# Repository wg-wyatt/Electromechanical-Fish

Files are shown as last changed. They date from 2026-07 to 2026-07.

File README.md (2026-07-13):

# Bio-Inspired Robotic Fish

## Overview

<p align="center">
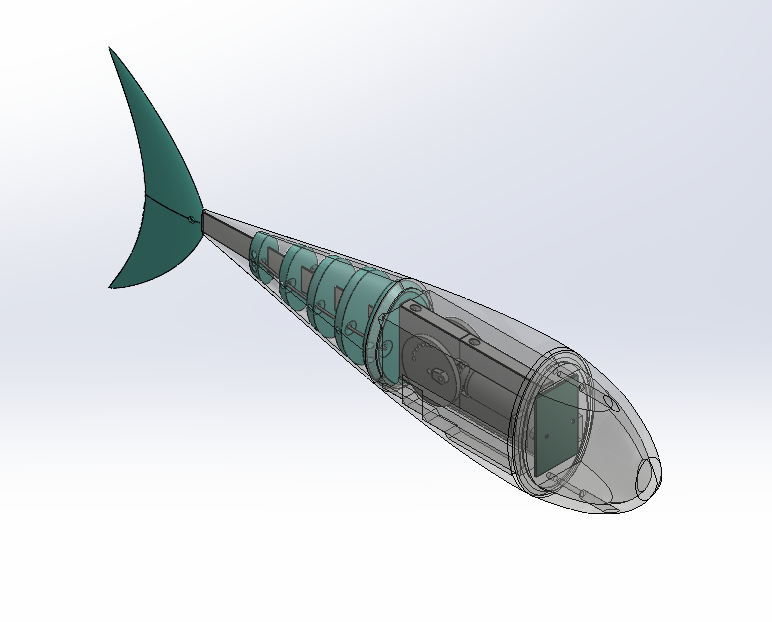
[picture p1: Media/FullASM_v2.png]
Bio-Inspired Robotic Fish Overview
  
</p>

<p align="center">
  <details>
    <summary>🔍 <b>Click to expand CAD Section & Internal Architecture View</b></summary>
    <br>
    <p align="center">
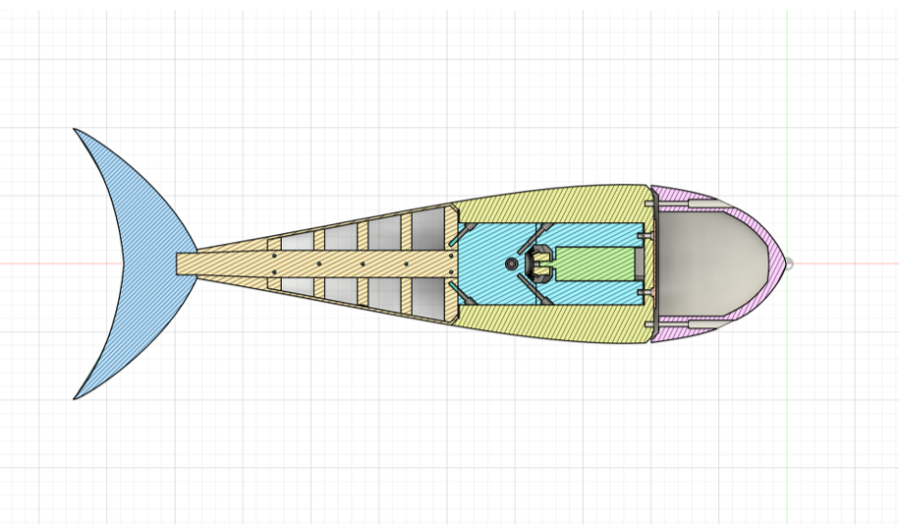
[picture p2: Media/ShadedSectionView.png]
Internal Architecture Blueprint
      
    </p>
  </details>
</p>

---

The Bio-Inspired Robotic Fish is an engineering project that uses undulatory propulsion (fish-like swimming) as an alternative to conventional propellers. The objective is to develop a modular robotic platform that mimics the biomechanics of carangiform swimmers using a mechanically actuated flexible body.

The project combines mechanism design, computational fluid dynamics (CFD), and rapid prototyping to integrate a rotary system that converts torque to smooth, oscillatory motion within a biomimetic frame. The project was developed as part of a physical prototyping class in which students designed and manufactured physical models for a speed competition.

---

## Project Objectives

The primary objectives of the project are to:

- Develop a mechanical system capable of converting a single rotary input into a traveling wave along a flexible body.
- Design a hydrodynamically efficient external body inspired by biological swimmers.
- Create a modular internal architecture that supports rapid iteration of actuators and transmission mechanisms.
- Evaluate propulsion concepts through physical prototyping.

---

## Problem Description

Conventional underwater vehicles primarily rely on propellers for propulsion. While effective, propellers generate noise, expose moving components, and are not optimized for maneuverability in confined or sensitive environments.

Many aquatic organisms instead produce propulsion by generating traveling waves along their bodies and fins. This method provides efficient thrust generation while enabling precise maneuvering and reduced acoustic signature.

This project explores the engineering challenges associated with reproducing this biological locomotion using practical mechanical systems and accessible manufacturing techniques. 

---

## Exterior Design

The external body is designed to balance hydrodynamic performance, manufacturability, and accessibility to internal components. Multiple design iterations are evaluated using CAD modeling and Computational Fluid Dynamics (CFD) to investigate body shape, drag characteristics, and flow behavior before fabrication.

Design considerations include:

- Streamlined body geometry
- Hydrodynamic efficiency
- Internal packaging volume
- Modular outer shell construction
- Ease of assembly and maintenance

CFD analysis was used during the design process to compare body geometries. Specific attention was given to drag coefficients when examining mechanisms to improve swimming velocity. Detailed CFD setup, mesh generation, and results are available in the analysis report:

[CFD Analysis Report](Analysis/CFD_report.pdf)

Shown in **Figure 1** is the final external design, which was modified from the surface model with the lowest drag coefficient and modularized into three compartments. Each compartment houses the electronics, the rotary actuator, and the spine used to generate the oscillation, respectively. 

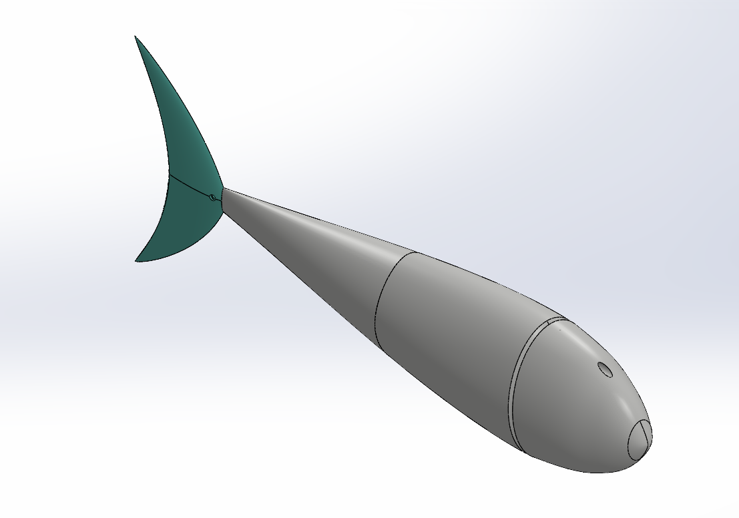
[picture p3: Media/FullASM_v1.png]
Robotic Fish Final Design


---

## Interior Design

The internal mechanical architecture focuses on generating undulatory motion using a compact rotary actuator and transmission mechanism. This design uses continuous rotary motion to produce a controlled traveling wave capable of propagating through a compliant tail section.

Current design investigations include:

- Motion transmission mechanisms
- Linkage geometry optimization
- Flexible body integration
- Waterproof packaging strategy

**Figure 2** displays the complete internal architecture, which is divided into three functional modules:

- *Module 1 (Front):* Houses the main electronics and battery payload. A secure gasket seals the interface between the first and second modules.

- *Module 2 (Central):* Encloses the motor gearbox and features integrated negative space for custom buoyancy weighting.

- *Module 3 (Rear):* Consists of the main undulating spine enclosed in a compliant silicone sleeve.

The gearbox mounts directly to the largest node of the spine, allowing the entire drive sub-assembly to slide seamlessly into the central chassis. Fastening the gearbox to the forward wall of Module 2 compresses the silicone sleeve, establishing a robust, watertight seal between the drive and tail sections.

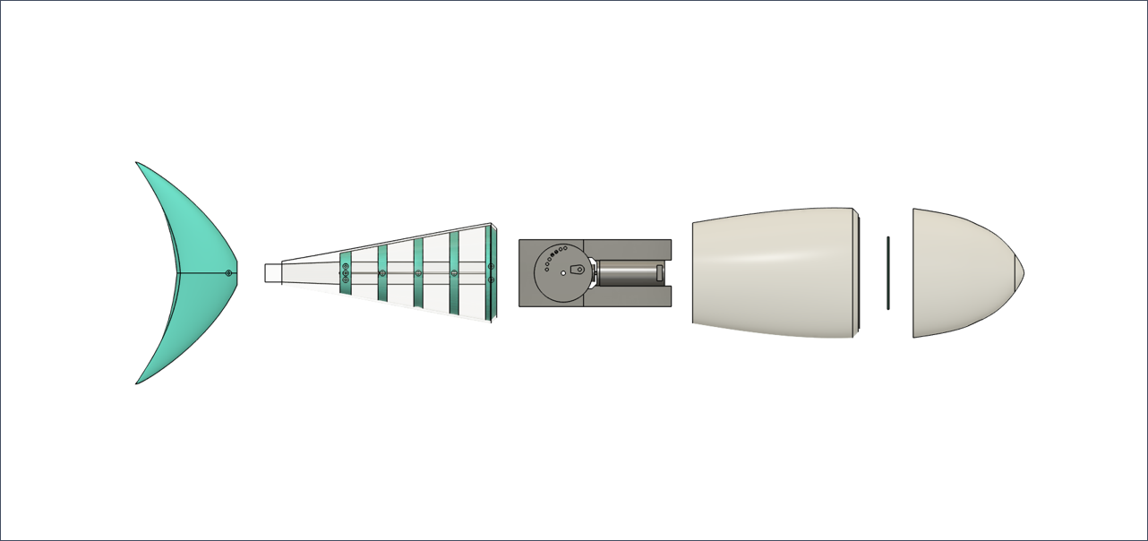
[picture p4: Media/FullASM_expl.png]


**Figure 3** illustrates the internal drive system, which is engineered to generate reciprocating motion that mimics the tandem contraction and expansion of biological fish musculature.

- *Torque Transmission:* A central drive gear translates power to two counter-rotating flywheels to balance inertial forces.

- *Adjustable Amplitude:* Multiple pinholes are integrated into the flywheels to allow for rapid physical experimentation with different oscillatory wave heights.

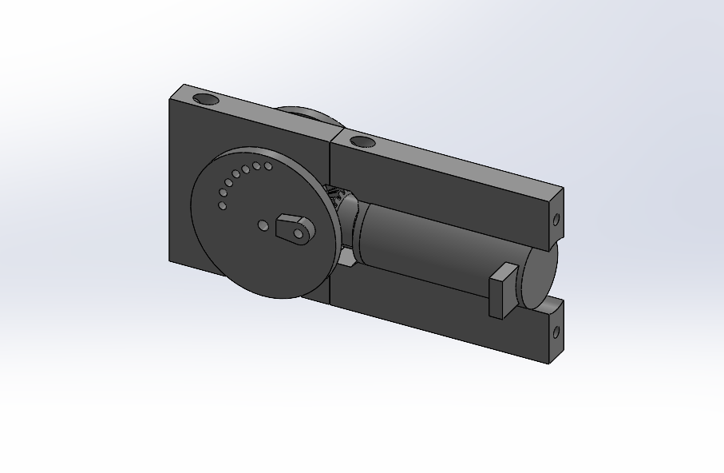
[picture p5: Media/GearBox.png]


<details>
  <summary>🔍 <b>Exploded View</b></summary>
  <p>
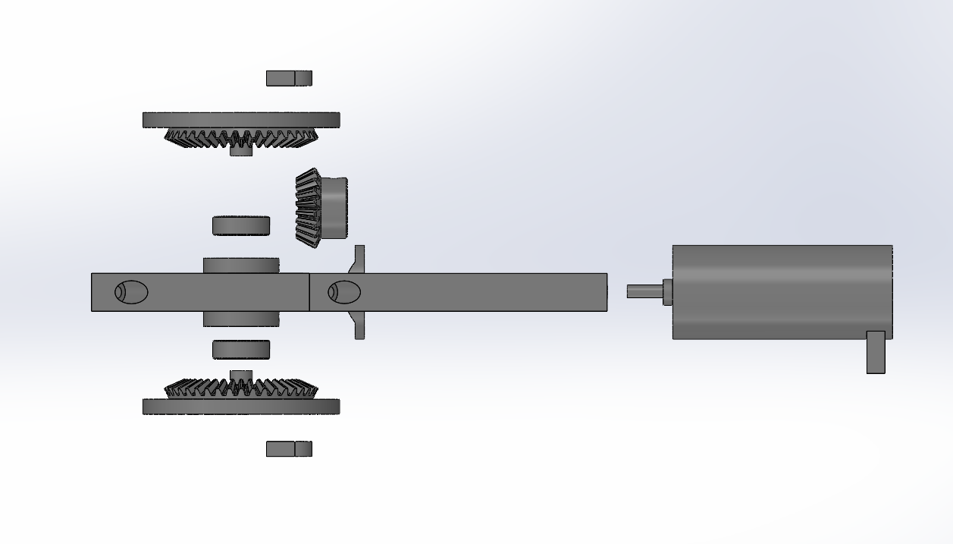
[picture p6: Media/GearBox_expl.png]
Exploded View
    
  </p>
</details>

**Figure 4** illustrates the spine system, which translates the rotational crank motion of the flywheels into the undulating wave profile that drives the tail fin. A flexible spine runs through five distinct nodes, which are linked to the flywheels via rigid PLA shafts. These push-pull linkages offer significantly higher structural rigidity and more precise force transmission than traditional steel cables or high-tensile ropes.

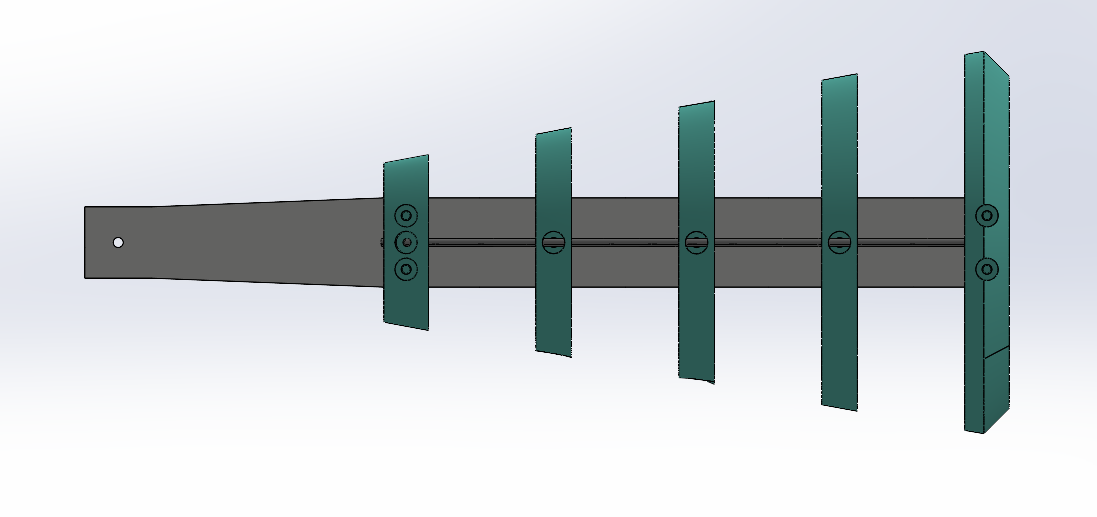
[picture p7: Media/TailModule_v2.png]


---

## Manufacturing

The robotic fish is designed around rapid prototyping techniques that enable fast design iteration while minimizing manufacturing cost and complexity.

### Pirmary Fabrication

**3D Printing:** 
- The main chassis modules
- The gear housings and components
-  Modular spine nodes
Components are designed with targeted orientation optimization to maximize layer adhesion against cyclic shear stresses generated during undulatory swimming.

**Laser Cutting:**
The central structural spine is precision laser-cut from acrylic sheets. This provides the bending stiffness required to guide the wave profile while maintaining structural rigidity.

**Silicone Molding:**
**Figure 5** illustrates the multi-part mold designed in SOLIDWORKS and 3D-printed to form the soft robotic component. A silicon epoxy is cast within the mold to produce the compliant outer casing required to seal the spine.

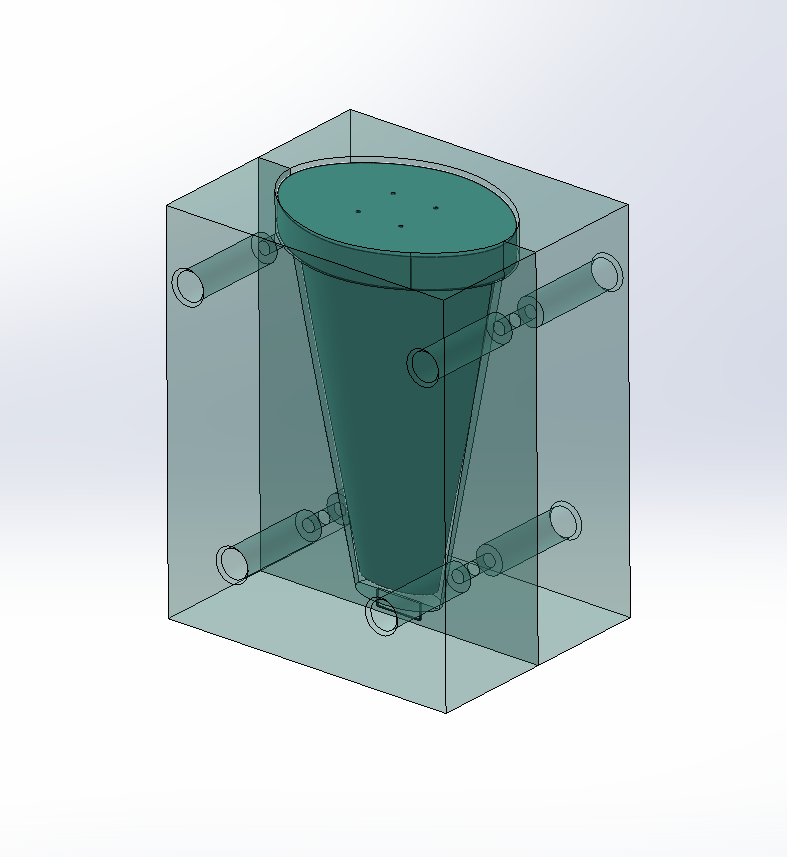
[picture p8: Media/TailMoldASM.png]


---

## Prototype Demonstration

The prototype was evaluated multiple times to optimize buoyancy and wave amplitude. **Figure 6** is a video log of a velocity test.

[<!-- Insert demonstration video here -->
<video src="Media/Prototype_Demo.mp4" width="100%" controls></video>](https://github.com/user-attachments/assets/9273b07a-2a17-41cb-9441-51ac28899b79)

---

## Skills Demonstrated

### Mechanical Design

- CAD modeling and assembly design
- Mechanical packaging
- Biomimetic engineering
- Actuator Integration
- Computational Fluid Dynamics (ANSYS Fluent)

### Manufacturing

- Design for additive manufacturing
- Laser-cut component
- Silicone molding
- Rapid prototyping

### Engineering Tools

- SolidWorks
- ANSYS Fluent
- 3D Printing
- Laser Cutting

---

## Acknowledgments

This project was completed as part of a robotics design course at Purdue University under the guidance of **Prof. Rob Scharff**.

Special thanks to the project team for their contributions:

- **Prof. Rob Scharff** – Project advisor and course instructor.
- **Artur Zhang** – Electrical Systems Lead, responsible for the electrical architecture and hardware integration.
- **Jonathan Wu** – Actuation Systems Lead, responsible for the development of the actuation subsystem and motion generation concepts.

Unless otherwise noted, the mechanical system design, CAD development, manufacturing strategy, engineering analysis, and project documentation presented in this repository represent my individual contributions. Team members are credited within specific files and documentation where they made direct contributions.

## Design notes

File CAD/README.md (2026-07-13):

# CAD Files

This folder contains simplified STEP exports of the primary robotic fish assemblies.

Included files:

- Fish_Assembly.step - Complete robotic fish assembly
- Gearbox_Module.step - Undulatory propulsion mechanism
- Actuation_Module.step - Internal actuation system

Commercial hardware and standard components have been simplified where appropriate.

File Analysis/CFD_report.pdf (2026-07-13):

## Overview

A computation fluid dynamics (CFD) analysis was performed to evaluate the drag characteristics of various exterior designs for a robotic fish. The objective was to compare external geometries to optimize hydrodynamic flow around the exterior while fulfilling internal packaging requirements for the actuations.

## Geometry

The model was validated using a body with a known drag coefficient. A benchmark was generated from a model used in the professor’s biomimicry research. Multiple external body geometries were evaluated to understand the effect of body shape on hydrodynamic performance.

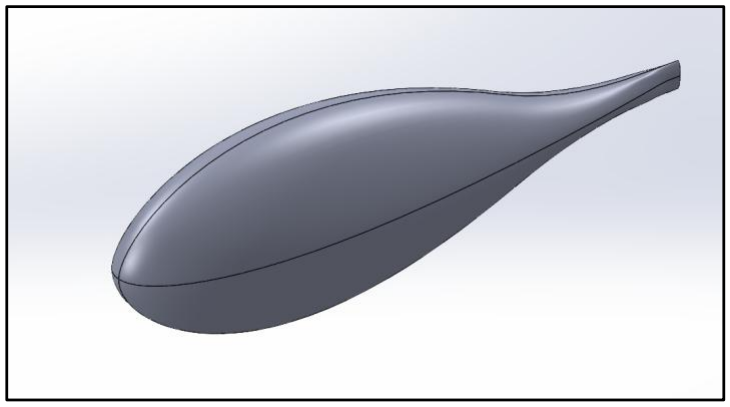
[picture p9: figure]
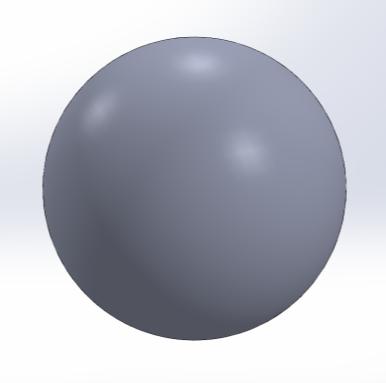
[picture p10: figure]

Figure 1. Validation Case | Figure 2. Benchmark

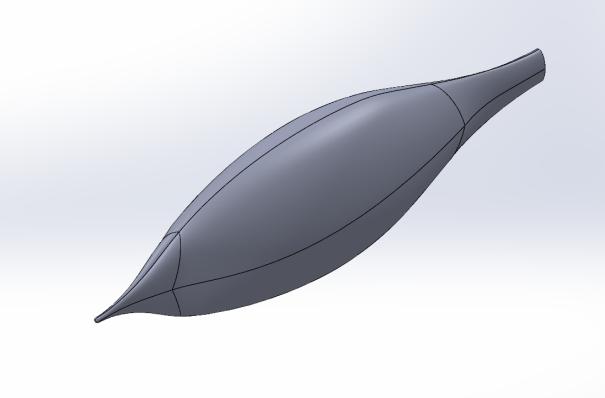
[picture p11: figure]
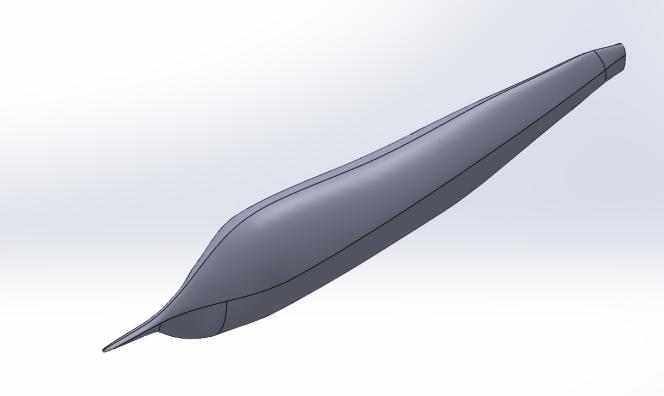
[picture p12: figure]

Figure 3. Sail Fish | Figure 4. Narwhal

## Simulation

The robotic fish geometry was imported into ANSYS Fluent for external flow evaluation. The simulation was configured to identify drag behavior of different body iterations by comparing drag coefficient values of bodies moving.

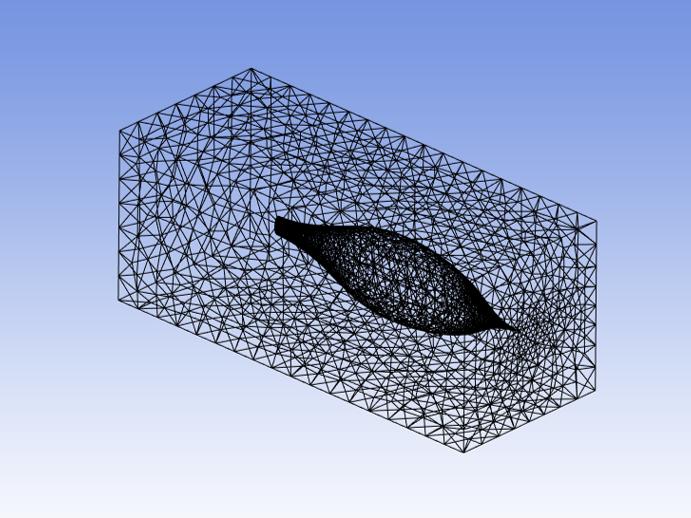
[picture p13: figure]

Figure 6. ANSYS Mechanical Mesh Example

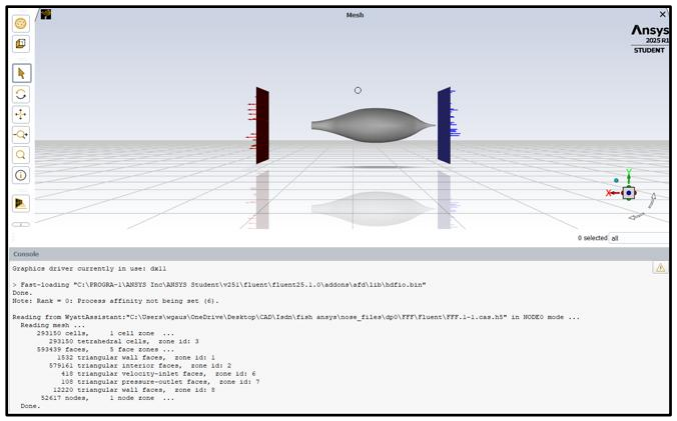
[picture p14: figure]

Figure 6. ANSYS Mechanical Mesh Example

## Results

Design | Drag Coefficient
Validation Case | 0.361392
Benchmark | 0.09990803
Sail Fish | 0.1341244
Narwhal | 0.1021232

## Conclusion

The CFD analysis was used to evaluate the effect of external body geometry changes on the hydrodynamic performance of the robotic fish design. A nose cone feature was investigated as a potential method for reducing flow separation and improving drag performance; however, the results showed that the addition of the nose cone did not provide a meaningful reduction in drag coefficient compared to the baseline geometry. A sailfish-inspired body profile was also evaluated due to its naturally streamlined shape, but the results indicated that this design did not provide a significant hydrodynamic advantage while increasing design complexity and limiting internal packaging space. Based on these results, the final design prioritized a balance between hydrodynamic performance, manufacturability, and integration of the internal actuation system.

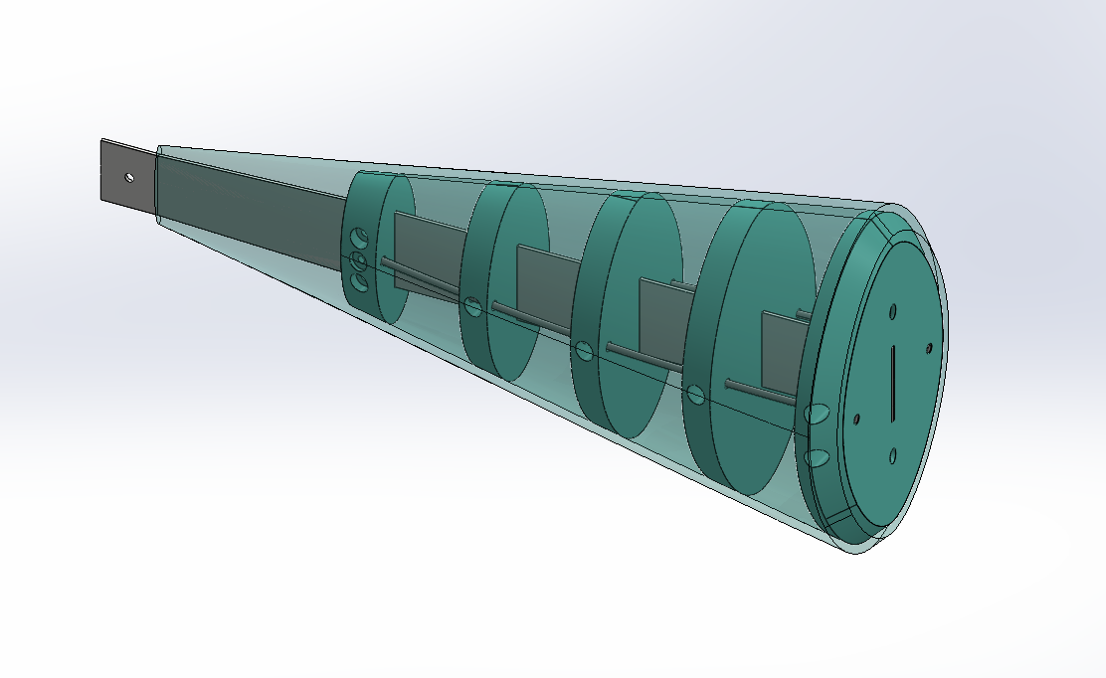
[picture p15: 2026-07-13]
Media/TailModule_v1.png

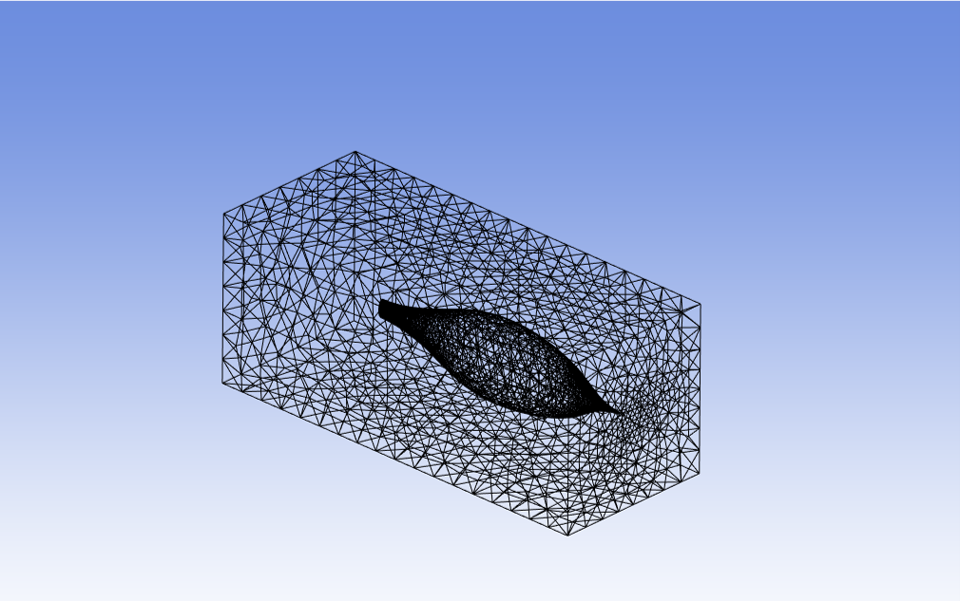
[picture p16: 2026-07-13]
Media/ANSYSmech_mesh.png

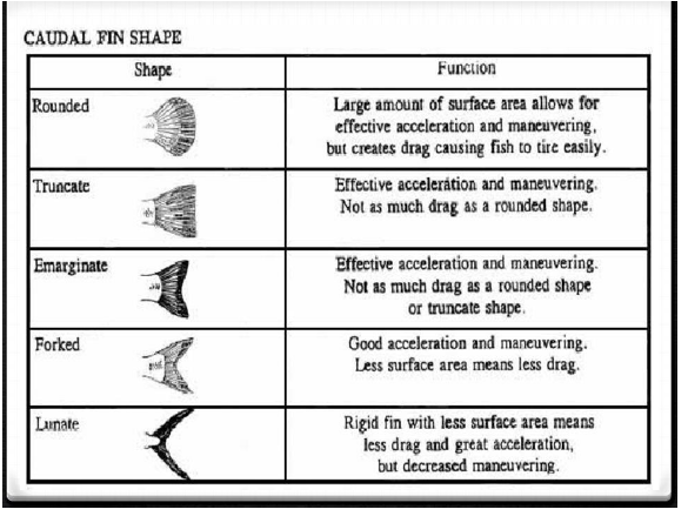
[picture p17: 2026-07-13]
Media/TailFinShape.png

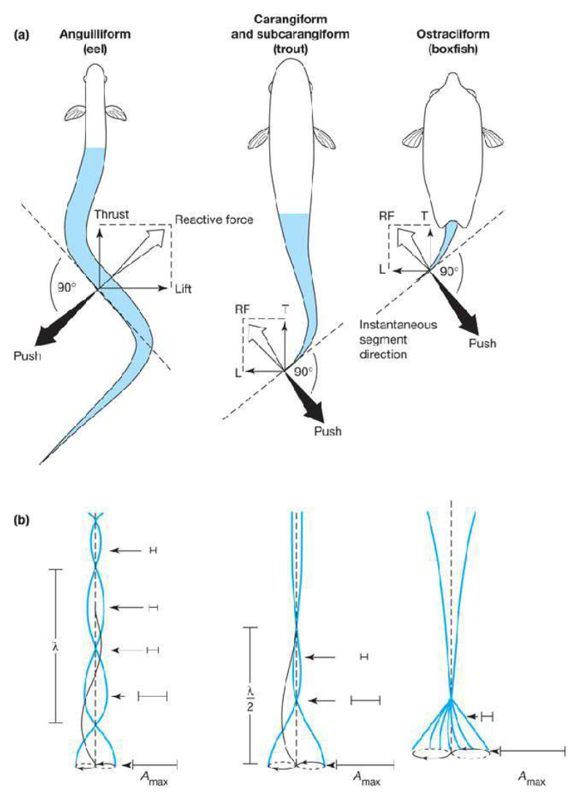
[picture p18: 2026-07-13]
Media/TailFinProfiles.png

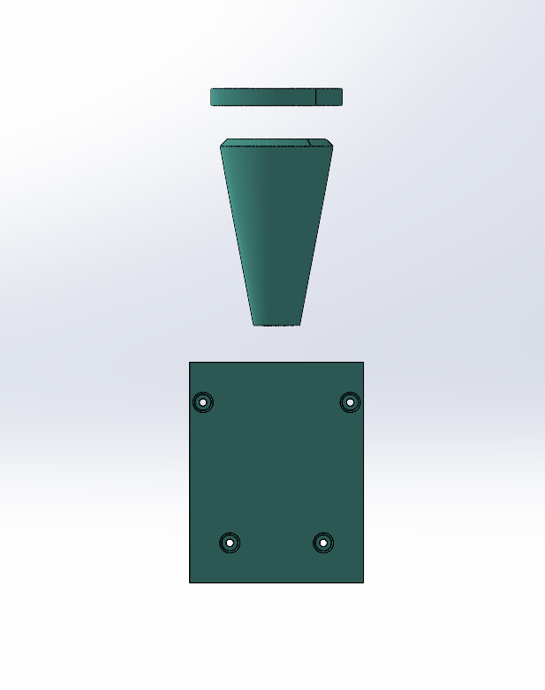
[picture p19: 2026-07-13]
Media/TailMoldASM_expl.png

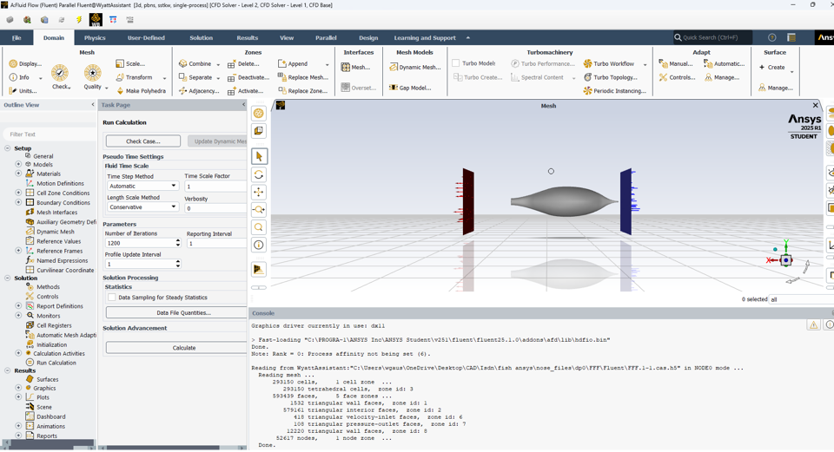
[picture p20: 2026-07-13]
Media/ANSYSfluent_model.png

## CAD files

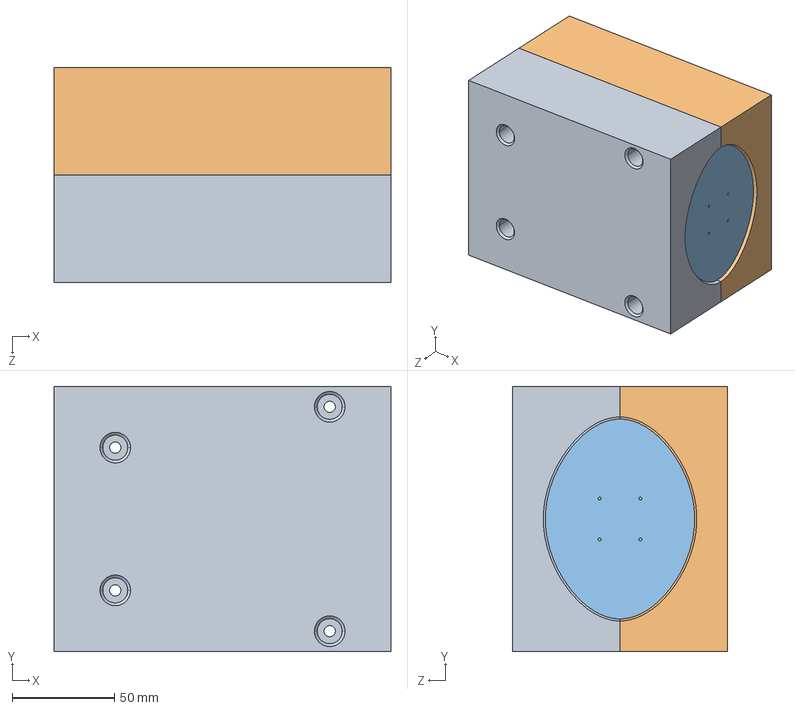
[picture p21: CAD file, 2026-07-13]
CAD/Tail_Mechanism.STEP
165.0 x 129.9 x 105.2 mm
tail mold
mold part 2
